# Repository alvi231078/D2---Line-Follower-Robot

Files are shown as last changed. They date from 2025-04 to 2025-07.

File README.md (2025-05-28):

# Intelligent Line Follower & Obstacle Color detector and Avoidance Robot

This robot uses IR sensors to follow a line, an ultrasonic sensor to detect obstacles, and a TCS3200 color sensor to detect colored zones (red, green, blue). If the color sensor is not connected, the robot will still function using IR and ultrasonic and IR sensors.

---

## 🛣 Line Following Logic

- **Sensor Input**:  
  - **Black surface** → `LOW`  
  - **White surface** → `HIGH`
  
- **Behavioral Responses**:
  - ➤ **Both sensors detect black** → Move straight
  - ➤ **One sensor detects white** → Adjust direction to stay on the line
  - ➤ **Both sensors detect white** → Line lost → Initiates recovery mode

---

## 🚧 Obstacle Avoidance Protocol

When an object is detected within **30-cm** using an ultrasonic sensor:

1. ➤ **Right Turn** – Exit the line path
2. ➤ **Forward Motion** – Navigate alongside the obstacle
3. ➤ **Left Turn** – Re-align with the original path
4. ➤ **Forward Motion** – Search and lock back onto the line

---

## 🎨 Color Sensor Behavior

If the optional TCS3200 color sensor is connected, the robot also responds to color:

- **Red** → Stop for 2 seconds  
- **Green** → Move forward faster  
- **Blue** → Turn right  
- **Unknown / No color** → Continue with normal behavior

> If the sensor is not connected, the robot continues using only IR and ultrasonic sensors.

---

## 🔌 Wiring Connections

### 🟦 Arduino UNO Pins

| Component | Pin on Arduino | Description |
|---|---|---|
| Left Motor | 9 | Left motor forward (PWM capable) |
| | 10 | Left motor backward |
| Right Motor | 5 | Right motor forward (PWM capable) |
| | 6 | Right motor backward |
| IR Sensor (Left)  | 2 | Digital input |
| IR Sensor (Right) | 3 | Digital input |
| Ultrasonic Sensor | 7 | Trigger pin |
| | 8 | Echo pin |
| Color Sensor S0 | 4 | Frequency scaling control |
| Color Sensor S1 | A0 | Frequency scaling control |
| Color Sensor S2 | A1 | Color filter selection |
| Color Sensor S3 | A2 | Color filter selection |
| Color Sensor OUT  | A3 | Frequency output |

---

## 🔋 Power Supply

- **Motors** should be powered using an external 6–12V battery (e.g., Li-Po).
- **Arduino UNO** can be powered via USB or VIN pin from the same battery.
- **IR, Ultrasonic, and Color Sensors** use 5V from the Arduino.

---

## ⚙️ Key Features

- ⏱️ **Non-Blocking Timers** – Efficient use of `millis()` for delay-free recovery  
- 🪛 **Debug with Ease** – Real-time diagnostics via `Serial Monitor`  
- 📦 **Modular Codebase** – Clear, reusable, and well-documented functions  

---

## 👨‍💻 Contributors

| Name | Title | Institution |
|---|---|---|
| **Md Ratul Ahmed Alvi** | Electronics Engineering Student  | Hochschule Hamm-Lippstadt |
| **Md Jubair Salehin Razin** | Electronics Engineering Student  | Hochschule Hamm-Lippstadt |
| **Faysal Ahammed Tonmoy** | Electronics Engineering Student  | Hochschule Hamm-Lippstadt |
| **Soaib Ferdous** | Electronics Engineering Student  | Hochschule Hamm-Lippstadt |

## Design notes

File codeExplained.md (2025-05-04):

🚗 Line Follower Robot – Project Description
Your project is a Line Follower Robot enhanced with obstacle avoidance capabilities using a state machine-based control system. Here's how it works step-by-step:

🔌 Startup
The robot begins in the Idle state after being powered on.

It transitions to LineFollowing when it receives a start command.

🧠 Core Behavior
In LineFollowing, the robot uses infrared (IR) sensors to follow a black line on the ground.

If no obstacle is detected, it keeps following the line.

If an obstacle is detected (via an ultrasonic sensor), it enters the ObstacleDetected state.

🕹️ Obstacle Avoidance
The robot stops and rotates a servo motor to scan its surroundings (ScanDirections).

It collects distance data from different directions (ChooseDirection) and selects the best path.

It then enters the BypassObstacle process, which decides whether to go right or left depending on available space.

🔄 Right or Left Bypass
In either RightBypass or LeftBypass, the robot:

Slightly turns in the chosen direction.

Moves forward, makes multiple turns to go around the obstacle.

Ends by searching for the original line again using its IR sensors.

👁️ Line Reacquisition
In LookForLineIR, the robot scans for the line.

Once the line is found (FinishBypass), it exits the bypass routine.

It returns to LineFollowing to continue on its path.

🛑 Shutdown
If the stop button is pressed or the battery is low, the robot enters the Stop state and powers off.

🧩 Key Technologies Involved:
IR sensors – For line tracking.

Ultrasonic sensor – For detecting obstacles.

Servo motor – For rotating and scanning directions.

State machine – To manage complex behaviors cleanly and modularly.

### 📘 `EXPLAIN.md` – Line-by-Line Code Explanation

```markdown
# 📘 Code Explanation – Line-Following Robot with Obstacle Avoidance

This document explains each section of the Arduino code used for an intelligent robot that can follow lines and avoid obstacles using ultrasonic and IR sensors.

---

## 🔧 Pin Definitions for car

```cpp
#define motorPin1 9
#define motorPin2 10
#define motorPin3 5
#define motorPin4 6
```
- These pins control the two DC motors via an H-bridge (e.g., L298N).

```cpp
#define TRIG_PIN 7
#define ECHO_PIN 8
```
- Ultrasonic sensor pins: `TRIG` sends a pulse, `ECHO` receives it.

```cpp
#define IR_LEFT 2
#define IR_RIGHT 3
```
- Left and right IR sensors for line detection.

```cpp
#define OBSTACLE_DISTANCE_THRESHOLD 30   // cm
#define RECOVERY_TIMEOUT 3000            // ms
#define AVOID_TIMEOUT 5000               // ms
```
- Constants for obstacle distance threshold and recovery timeouts.

---

## 🏁 setup()

```cpp
void setup() {
  // Set motor, ultrasonic, and IR pins
  pinMode(...);
  Serial.begin(9600);
}
```
- Prepares all input/output pins.
- Starts serial monitor for debugging and logs.

---

## 🔄 loop()

```cpp
long distance = getDistance();
bool leftIR = digitalRead(IR_LEFT);
bool rightIR = digitalRead(IR_RIGHT);
```
- Reads obstacle distance and IR sensor values (`LOW` = black line).

### Logging

```cpp
Serial.print("Distance: ");
Serial.println(distance);
```
- Shows real-time sensor data in the Serial Monitor.

### Obstacle Check

```cpp
if (distance < OBSTACLE_DISTANCE_THRESHOLD) {
  avoidObstacle();
  return;
}
```
- If the robot sees an obstacle within 30 cm, it performs a detour.

### Line Following

```cpp
if (!leftIR && !rightIR) moveForward();
else if (!leftIR && rightIR) turnLeft();
else if (leftIR && !rightIR) turnRight();
else recoverLine();
```
- Line-following logic using 2 IR sensors.

---

## 📏 getDistance()

```cpp
digitalWrite(TRIG_PIN, HIGH);
long duration = pulseIn(ECHO_PIN, HIGH, 20000);
return duration * 0.034 / 2;
```
- Measures time taken for sound to bounce back and converts to distance.
- Includes timeout of 20 ms to avoid sensor hang.

---

## 🚗 Motor Functions

```cpp
moveForward()
stopMotors()
turnLeft()
turnRight()
```
- Control robot movement by setting motor pins HIGH or LOW.

---

## 🔀 avoidObstacle()

```cpp
turnRight(); delay(400);
moveForward(); check distance;
turnLeft(); delay(400);
moveForward(); delay(500);
recoverLine();
```
- Turns away from obstacle, moves forward beside it, then returns to line.
- Uses timeout to avoid getting stuck in obstacle avoidance mode.

---

## ♻️ recoverLine()

```cpp
spin right slowly until IR_LEFT or IR_RIGHT sees black
```
- Spins in place to search for the black line.
- Times out if line isn't found within `RECOVERY_TIMEOUT`.

---

## ✅ Built-In Safety & Reliability

- **Timeouts**: Prevent infinite loops (e.g. in line recovery).
- **Distance Thresholds**: Stops or avoids collisions.
- **Failsafe Spins**: Robot always tries to recover or move forward.

---

## 📚 Further Ideas

- Use 3 IR sensors (left, center, right) for smoother detection.
- Replace `delay()` with `millis()` for non-blocking movement.
- Add `analogWrite()` (PWM) for speed control.
- Add remote or app-based control override.

---

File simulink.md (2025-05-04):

# 🚗 Line Follower Robot using MATLAB Simulink

This project demonstrates how to simulate and deploy an autonomous **line follower vehicle** using **MATLAB Simulink** and **Arduino Uno**. It uses **IR sensors** to detect the line path and controls the direction of two DC motors via **L298N Motor Driver**.

## 🛠 Hardware Used

* Arduino Uno
* 2 × DC Motors
* L298N Dual H-Bridge Motor Driver
* 2 × IR Sensors (Digital)
* Jumper wires, breadboard
* Optional: Ultrasonic sensor, TCS3200/TCS34725 (future)

## 🧱 Simulink Blocks Used

* **Digital Input** (IR\_LEFT: D2, IR\_RIGHT: D3)
* **Digital Output** (Motor Pins: D5, D6, D9, D10)
* **Logic Gates** (NOT, AND)
* **Multiport Switch**
* **Constant Blocks** (simulate logic levels)
* **Goto/From Tags** (signal routing)
* **Switch Block** (decision logic for motor direction)

## 🧠 Logic Overview

### IR Sensor Logic:

| IR\_LEFT | IR\_RIGHT | Action |
| --- | --- | --- |
| 0 | 0 | Stop |
| 0 | 1 | Turn Left |
| 1 | 0 | Turn Right |
| 1 | 1 | Move Forward |

### Motor Logic:

* Each motor has 2 input pins controlled through **multiport switches**.
* Based on the IR logic, control signals are routed to the motor inputs to drive the vehicle in the required direction.

## ✅ Current Features

* Complete **IR-based line-following logic**
* Simulates **four movement states**: Stop, Left, Right, Forward
* Multiport logic linked to motor pins:

  * Motor A: D9 (IN1), D10 (IN2)
  * Motor B: D5 (IN3), D6 (IN4)
* Built using modular **logic blocks** for learning and clarity

## 🧪 How to Test

1. Open the `line_follower_vehicle_Simulink.slx` in Simulink.
2. Ensure **Simulink Support Package for Arduino** is installed.
3. Set **hardware board** to "Arduino Uno" in Model Settings.
4. Use simulation or **Deploy to Hardware**.
5. Place the robot on a black line and observe motor reaction to IR input conditions.

## 🔮 Future Enhancements

* Add **Ultrasonic sensor** (`HC-SR04`) with **servo motor** for obstacle detection
* Add **Color Detection Sensor** (`TCS3200` or `TCS34725`) for object interaction
* Apply **PID control** for smoother turns
* Optimize logic using **Stateflow**

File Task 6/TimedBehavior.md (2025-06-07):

Timed Behavior – Task 6

This UPPAAL model simulates the obstacle-handling logic of the line-following robot, including:

Obstacle detection using distance

Color-based routing (red = avoid, blue = push)

Timed transitions using a clock x to simulate delays in real-world actuation (e.g., motor turning, scanning)

⏱️ Timing constraints are modeled using guards (x ≥ N) and invariants (x ≤ N) to reflect Arduino delays.

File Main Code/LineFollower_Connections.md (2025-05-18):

# Line Follower Robot with Motor Driver and IR Sensors

This project is a simple line follower robot using two digital IR sensors and a motor driver to control two DC motors (left and right). The robot follows a black line on a white surface by reading sensor inputs and controlling motor speed and direction accordingly.

---

## Hardware Connections

### Motor Driver Pins
| Pin | Description |
|---|---|
| 10 | ENA - PWM Motor A (Left Motor Speed Control) |
| 11 | ENB - PWM Motor B (Right Motor Speed Control)  |
| 5 | IN1 - Motor A Input 1 (Left Motor Direction) |
| 6 | IN2 - Motor A Input 2 (Left Motor Direction) |
| 7 | IN3 - Motor B Input 1 (Right Motor Direction)  |
| 8 | IN4 - Motor B Input 2 (Right Motor Direction)  |

### IR Sensor Pins (Digital)
| Pin | Description |
|---|---|
| 3 | Left IR Sensor |
| 4 | Right IR Sensor |

---

## Speed Settings

| Variable | Value | Description |
|---|---|---|
| `baseSpeed` | 65 | Normal forward speed (PWM) |
| `maxSpeed` | 90 | Maximum speed (not used in code) |
| `reverseSpeed` | 60 | Speed when reversing |

---

## How It Works

- The robot reads the state of two IR sensors (`leftSensorPin` and `rightSensorPin`).
- Both sensors LOW: Robot moves forward.
- Left sensor HIGH, right sensor LOW: Robot turns left.
- Left sensor LOW, right sensor HIGH: Robot turns right.
- Both sensors HIGH: Robot reverses to search for the line.

---

## Functions

- `moveForward(speed)`: Drives both motors forward at the specified speed.
- `turnLeft(speed)`: Stops left motor and runs right motor forward to turn left.
- `turnRight(speed)`: Runs left motor forward and stops right motor to turn right.
- `moveBackward(speed)`: Drives both motors backward at the specified speed.

---

## Usage

1. Connect your motors and IR sensors as described in the Hardware Connections.
2. Upload the provided Arduino sketch to your microcontroller.
3. Place the robot on a black line on a white surface and power it on.
4. The robot will follow the line by continuously adjusting its motor speeds based on sensor inputs.

---

## Notes

- Make sure your IR sensors are calibrated properly for the surface colors.
- Adjust `baseSpeed` and `reverseSpeed` values if needed for better line tracking.
- `maxSpeed` is defined but not used in the current code. You can modify the code to utilize it if required.

---

## License

This project is open source and free to use.

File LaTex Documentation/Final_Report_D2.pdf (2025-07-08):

# Design and Implementation of a Line Following and Obstacle Avoidance Robot

## ( Final Technical Report)

Team D2: Faysal Ahammed Tonmoy, Jubair Salehin Razin, Md Ratul Ahmed Alvi, Soaib Ferdous Prototyping and Systems Engineering
BSc Electronic Engineering Hochschule Hamm-Lippstadt, Lippstadt, Germany

Abstract—This paper presents the design, development, and implementation of an Arduino-based robot capable of following a black line and avoiding obstacles in its path. The system integrates IR sensors for line detection and an ultrasonic sensor mounted on a servo motor for environmental scanning. The robot’s decision-making algorithm enables smooth path-following while dynamically reacting to obstacles. Both hardware and software components were prototyped virtually before realworld testing. Results show reliable performance in various test scenarios.

Index Terms—Line follower robot, Obstacle avoidance, Arduino, Servo motor, Ultrasonic sensor

I. SYSTEM MODELING USING SYSML

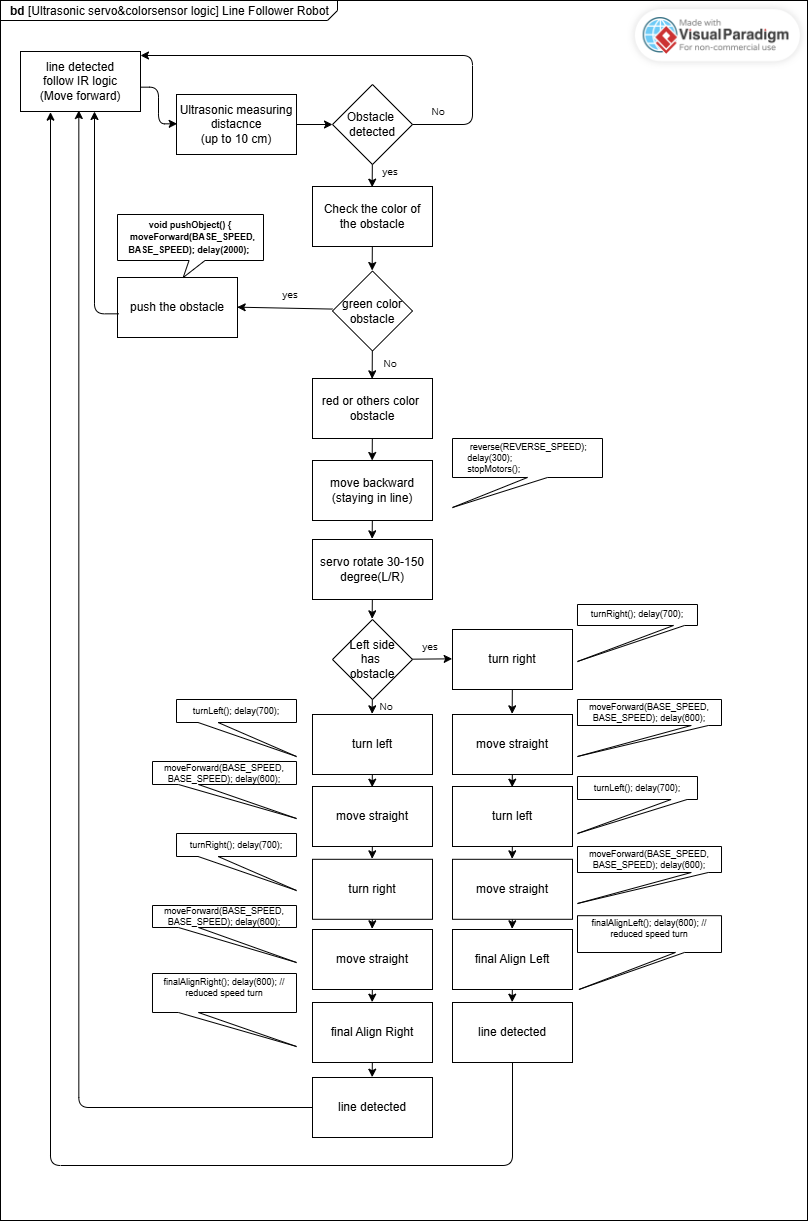
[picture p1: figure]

Fig. 1. Overall System Block Diagram of the Robot

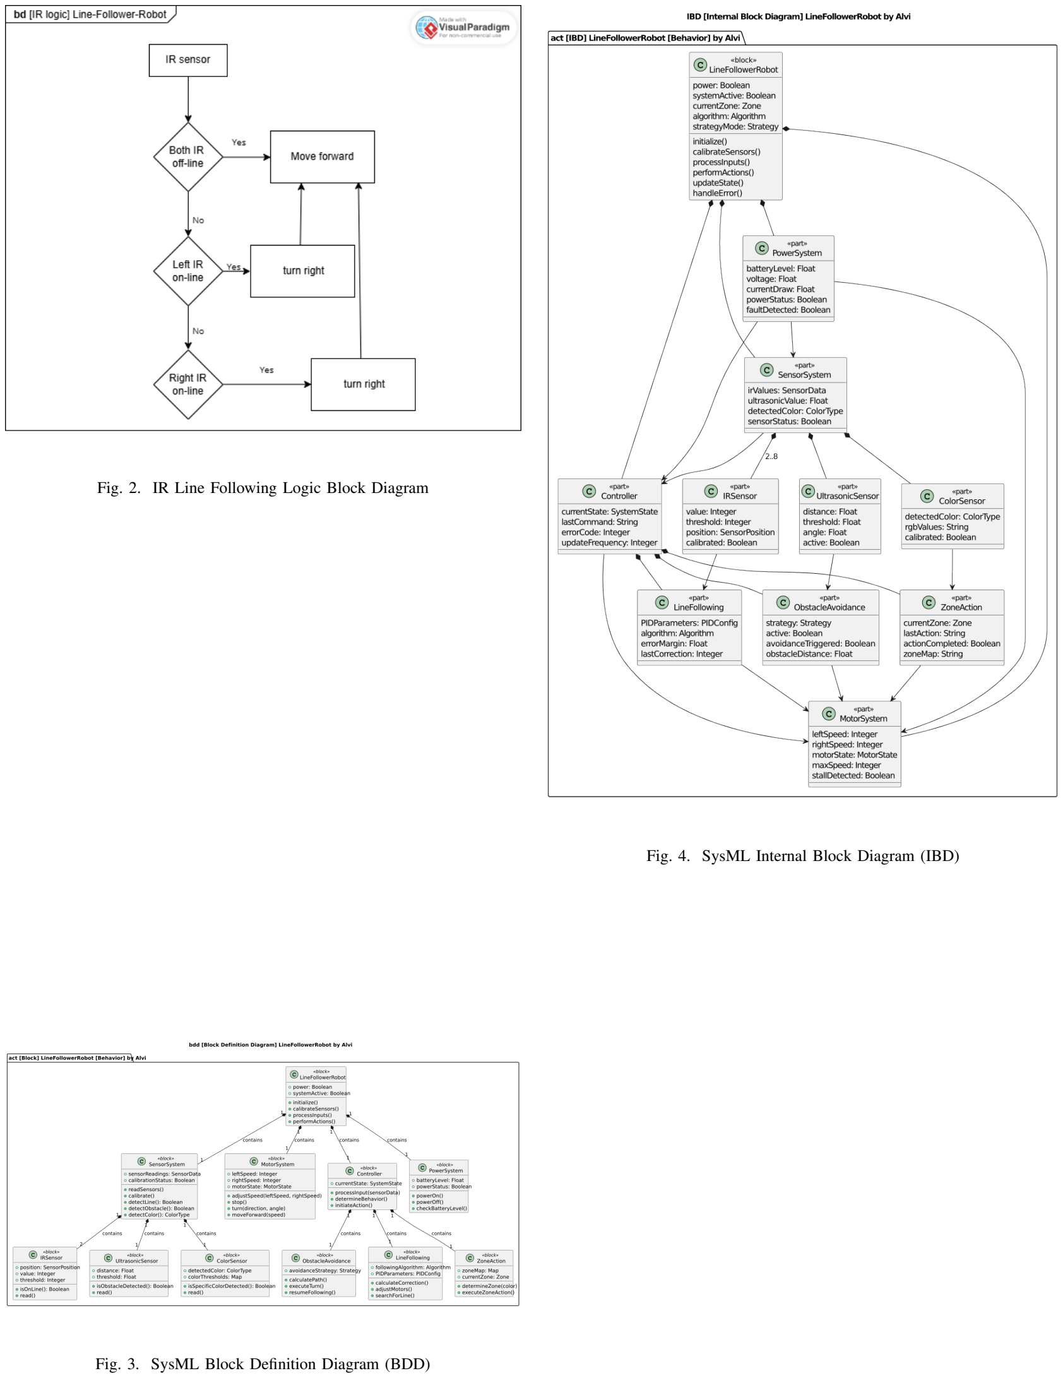
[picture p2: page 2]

Fig. 2. IR Line Following Logic Block Diagram

Fig. 3. SysML Block Definition Diagram (BDD)

Fig. 4. SysML Internal Block Diagram (IBD)

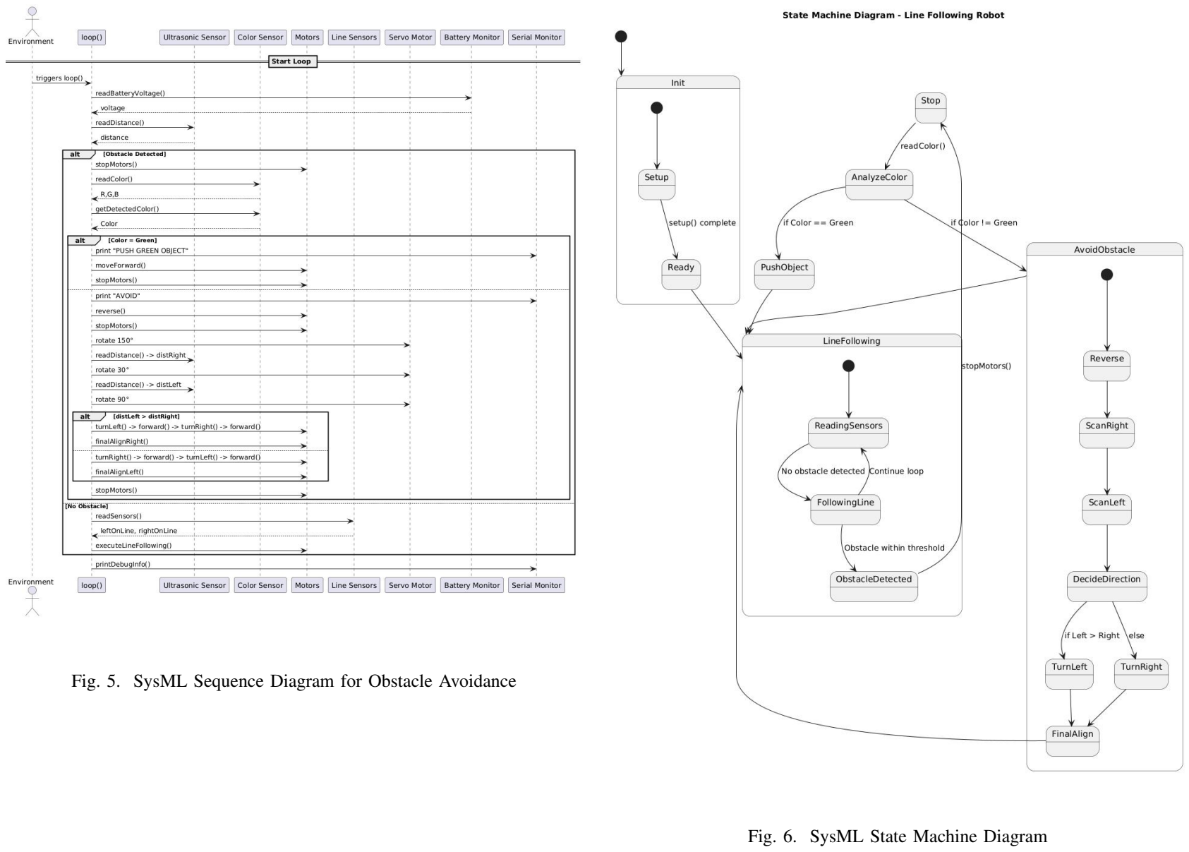
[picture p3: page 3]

Fig. 5. SysML Sequence Diagram for Obstacle Avoidance

Fig. 6. SysML State Machine Diagram

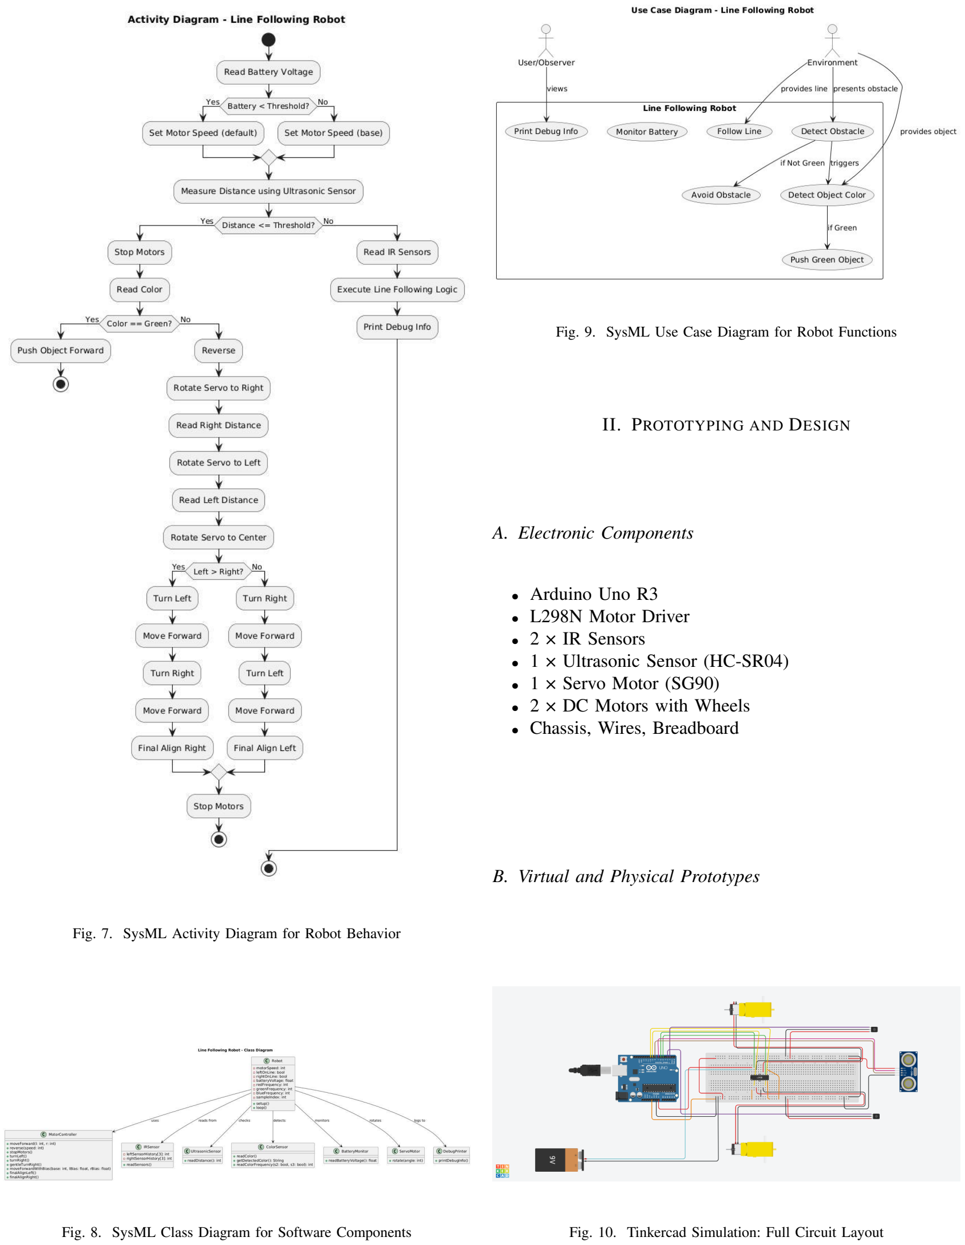
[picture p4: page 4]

Fig. 7. SysML Activity Diagram for Robot Behavior

Fig. 8. SysML Class Diagram for Software Components

Fig. 9. SysML Use Case Diagram for Robot Functions

II. PROTOTYPING AND DESIGN

A. Electronic Components
- Arduino Uno R3
- L298N Motor Driver
- 2 × IR Sensors
- 1 × Ultrasonic Sensor (HC-SR04)
- 1 × Servo Motor (SG90)
- 2 × DC Motors with Wheels
- Chassis, Wires, Breadboard
B. Virtual and Physical Prototypes

Fig. 10. Tinkercad Simulation: Full Circuit Layout

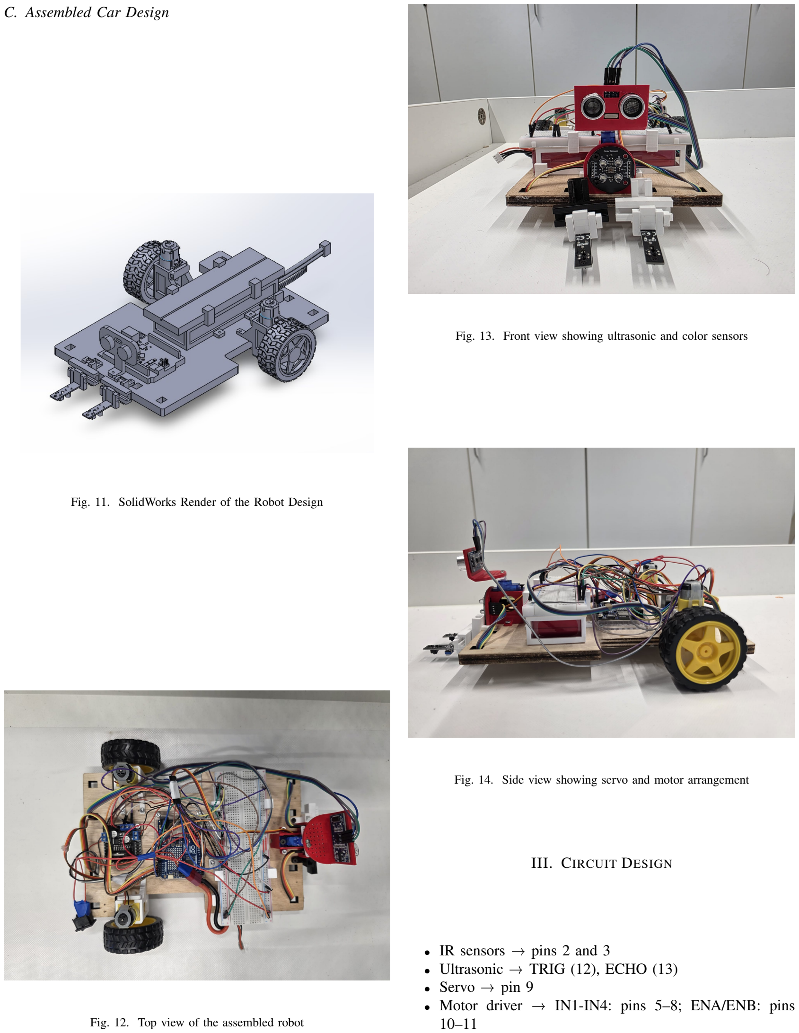
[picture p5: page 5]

C. Assembled Car Design

Fig. 11. SolidWorks Render of the Robot Design

Fig. 12. Top view of the assembled robot

Fig. 13. Front view showing ultrasonic and color sensors

Fig. 14. Side view showing servo and motor arrangement

III. CIRCUIT DESIGN

- IR sensors pins 2 and 3
- Ultrasonic TRIG (12), ECHO (13)
- Servo pin 9
- Motor driver IN1-IN4: pins 5–8; ENA/ENB: pins 10–11

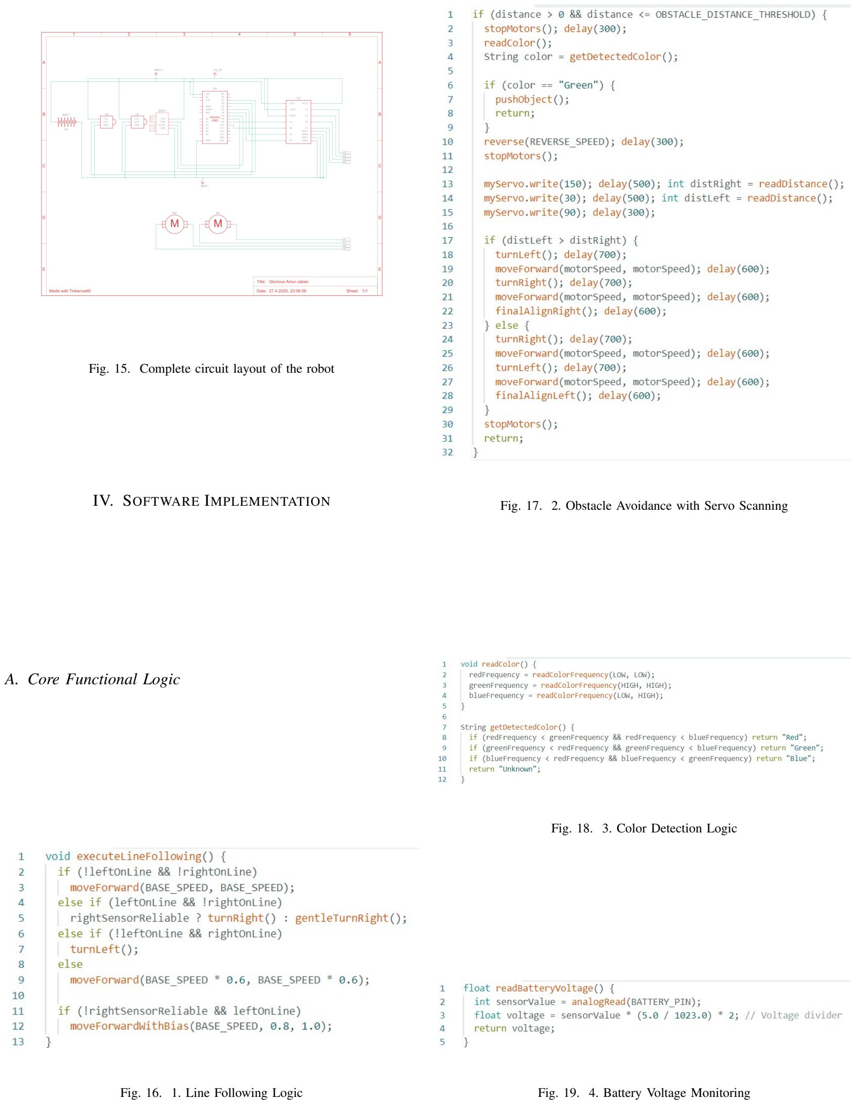
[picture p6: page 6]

Fig. 15. Complete circuit layout of the robot

IV. SOFTWARE IMPLEMENTATION

A. Core Functional Logic

Fig. 16. 1. Line Following Logic

Fig. 17. 2. Obstacle Avoidance with Servo Scanning

Fig. 18. 3. Color Detection Logic

Fig. 19. 4. Battery Voltage Monitoring

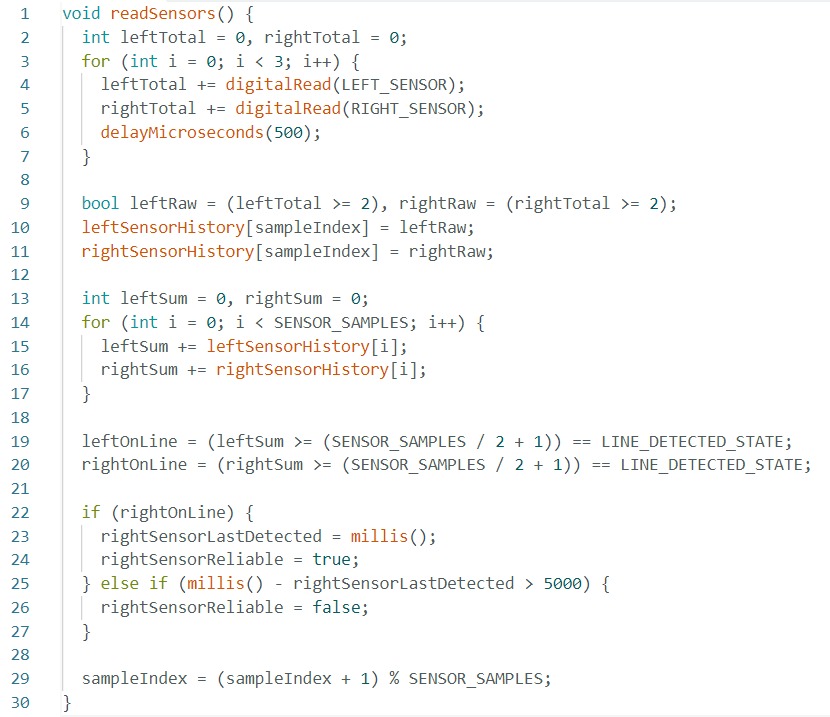
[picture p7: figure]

Fig. 20. 5. Sensor Filtering for Stability

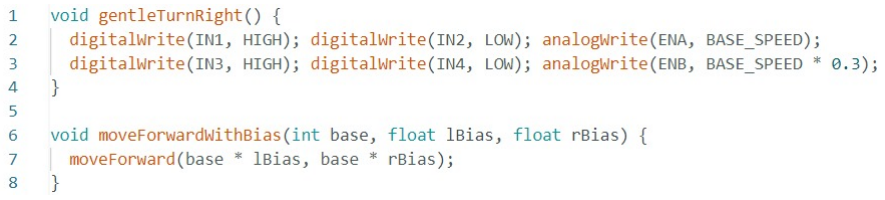
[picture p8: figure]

Fig. 21. 6. Differential Speed for Smooth Turns

B. A. UPPAAL Simulation

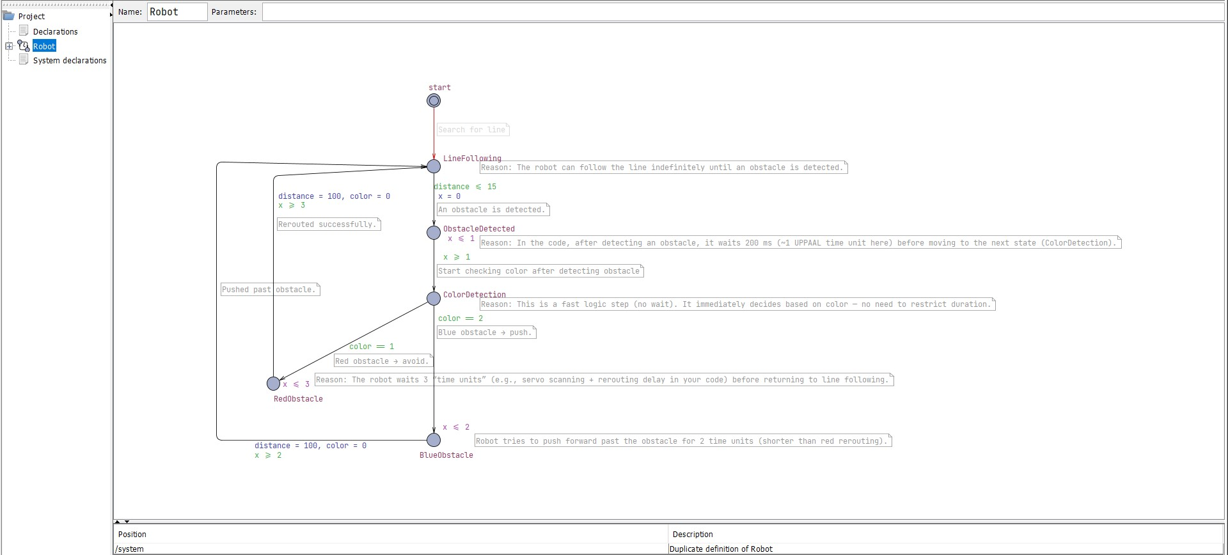
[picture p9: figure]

Fig. 22. UPPAAL Timed Automata Model for Robot Control

C. B. LTspice Simulation

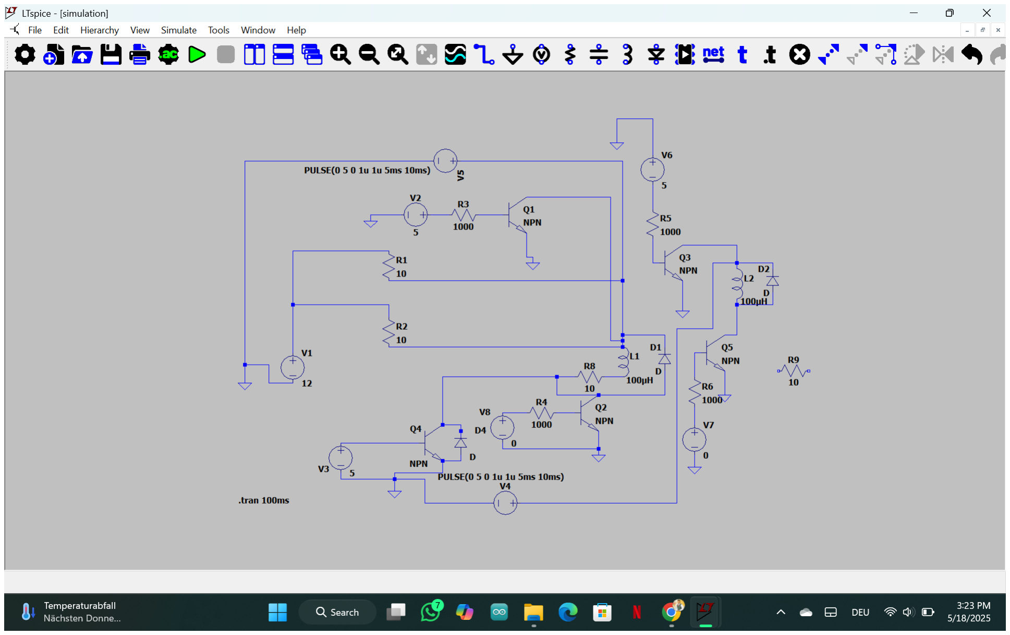
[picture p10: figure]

Fig. 23. LTspice Motor Driver Circuit Simulation

V. GIT USAGE AND COLLABORATION
- Jubair Salehin Razin: Simulation, testing, software logic, hardware integration
- Md Ratul Ahmed Alvi: Arduino coding, debugging, wiring and logic testing
- Faysal Ahammed Tonmoy: Documentation, CAD, simulations, integration
- Soaib Mahin Ferdous: Diagram creation, documentation, support tasks
Team Member | Commits
Faysal Ahammed Tonmoy | 90
Jubair Salehin Razin | 148
Md Ratul Ahmed Alvi | 162
Soaib Mahin Ferdous | 36
Total | 436
TABLE I
GITHUB COMMITS BY TEAM MEMBERS

VI. KEY ACHIEVEMENTS

- Built a reliable, intelligent robot system
- Designed and printed all mechanical parts in SolidWorks
- Simulated logic and hardware in Tinkercad, UPPAAL, LTspice
- Documented system architecture using SysML
- Worked collaboratively using GitHub

VII. CONCLUSION AND FUTURE WORK

The robot successfully integrates sensor data and motor control to follow a black line while avoiding obstacles. Future enhancements may include path memory, camera-based vision, Bluetooth control, and autonomous charging.

ACKNOWLEDGMENT

We sincerely thank our professor for their guidance, feedback, and encouragement throughout this project. We also appreciate the support from lab assistants and the facilities provided by Hochschule Hamm-Lippstadt, which were essential to our development and testing. Finally, we acknowledge the teamwork and dedication of all members that made this project a success.

REFERENCES

[1] Arduino Documentation. https://www.arduino.cc/en/Guide
[2] Tinkercad Simulation. https://www.tinkercad.com
[3] Uppaal Model Checker. http://www.uppaal.org/
[4] LTspice | Simulator. | https://www.analog.com/en/design-center/
design-tools-and-calculators/ltspice-simulator.html (https://www.analog.com/en/design-center/design-tools-and-calculators/ltspice-simulator.html)

DECLARATION OF ORIGINALITY
We hereby declare that this report is our own work and that we have acknowledged all sources used.
Faysal Ahammed Tonmoy
Jubair Salehin Razin
Md Ratul Ahmed Alvi
Soaib Ferdous

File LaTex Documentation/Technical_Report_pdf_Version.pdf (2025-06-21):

# Design and Implementation of a Line Following and Obstacle Avoidance Robot

## (Technical Report)

Team D2: Faysal Ahammed Tonmoy, Jubair Salehin Razin, Md Ratul Ahmed Alvi, Soaib Ferdous Prototyping and Systems Engineering BSc Electronic Engineering Hochschule Hamm-Lippstadt
Lippstadt, Germany

Abstract—This paper presents the design, development, and implementation of an Arduino-based robot capable of following a black line and avoiding obstacles in its path. The system integrates IR sensors for line detection and an ultrasonic sensor mounted on a servo motor for environmental scanning. The robot’s decision-making algorithm enables smooth path-following while dynamically reacting to obstacles. Both hardware and software components were prototyped virtually before real-world testing. Results show reliable performance in various test scenarios.

Index Terms—Line follower robot, Obstacle avoidance, Arduino, Servo motor, Ultrasonic sensor

I. INTRODUCTION

Line-following and obstacle-avoiding robots are fundamental projects in the field of robotics and embedded systems. These robots offer practical insights into sensor integration, motor control, decision-making algorithms, and real-time behavior. Such applications are widely used in industrial automation, delivery robots, and warehouse management systems.

This project focuses on the design and development of a mobile robot that can autonomously follow a predefined path while detecting and avoiding obstacles using infrared (IR) and ultrasonic sensors. The integration of hardware and software components was achieved through iterative prototyping, simulation (using Tinkercad), and formal verification using UPPAAL to ensure time-critical responsiveness.

The objective was to create a low-cost, Arduino-based robot capable of smart navigation in dynamic environments, with collaborative development managed via Git and GitHub.

II. SYSTEM MODELING USING SYSML

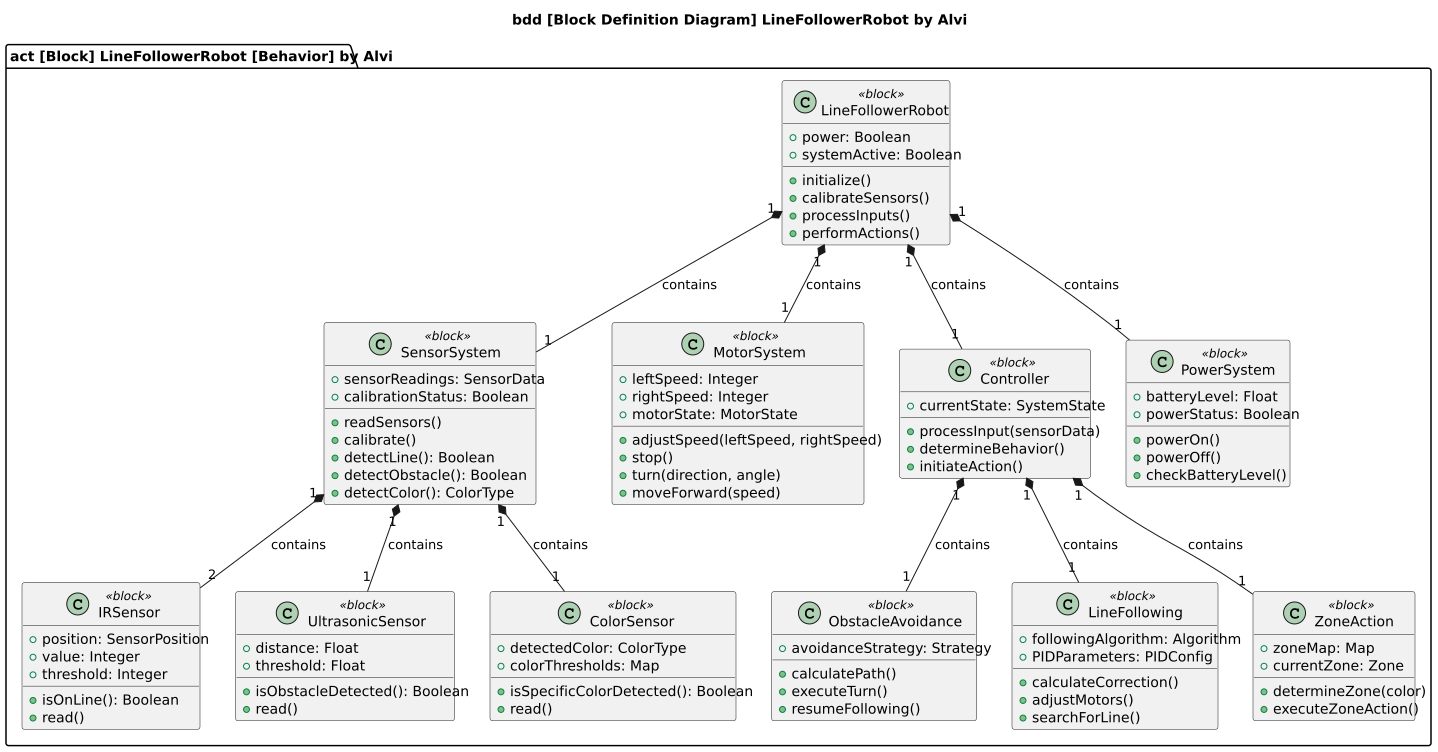
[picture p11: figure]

Fig. 1. SysML Block Definition Diagram (BDD)

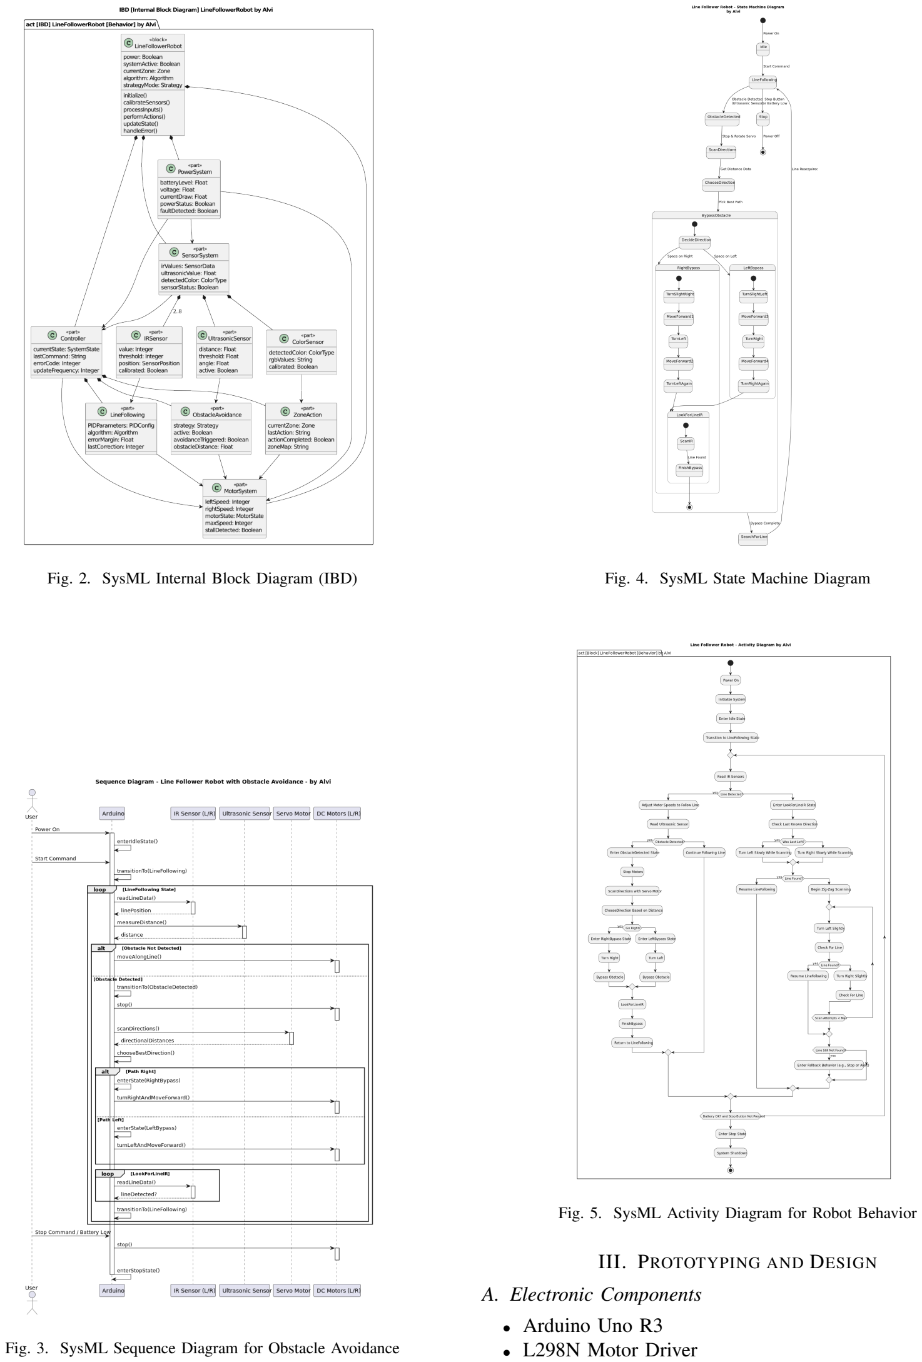
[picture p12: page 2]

Fig. 2. SysML Internal Block Diagram (IBD)

Fig. 3. SysML Sequence Diagram for Obstacle Avoidance

Fig. 4. SysML State Machine Diagram

Fig. 5. SysML Activity Diagram for Robot Behavior

III. PROTOTYPING AND DESIGN

A. Electronic Components
- Arduino Uno R3
- L298N Motor Driver

- 2 × IR Sensors
- 1 × Ultrasonic Sensor (HC-SR04)
- 1 × Servo Motor (SG90)
- 2 × DC Motors with Wheels
- Chassis, Wires, Breadboard
B. Virtual and Physical Prototypes

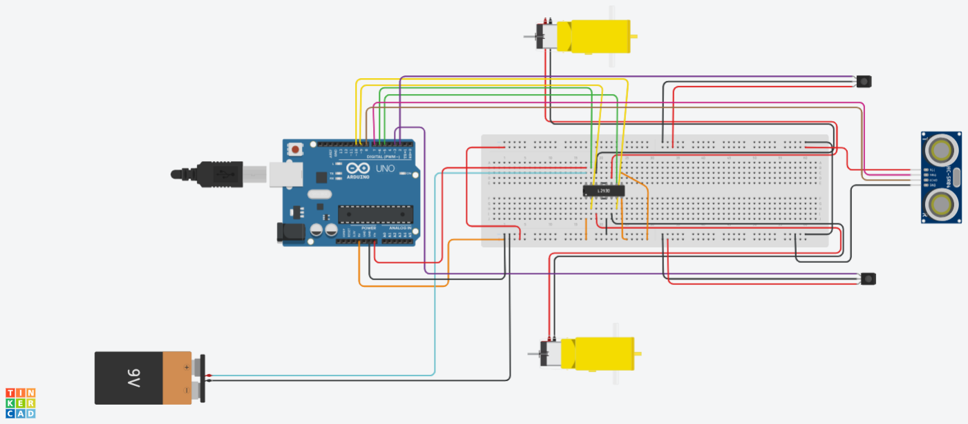
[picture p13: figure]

Fig. 6. Tinkercad Simulation: Full Circuit Layout

C. Assembled Car Design

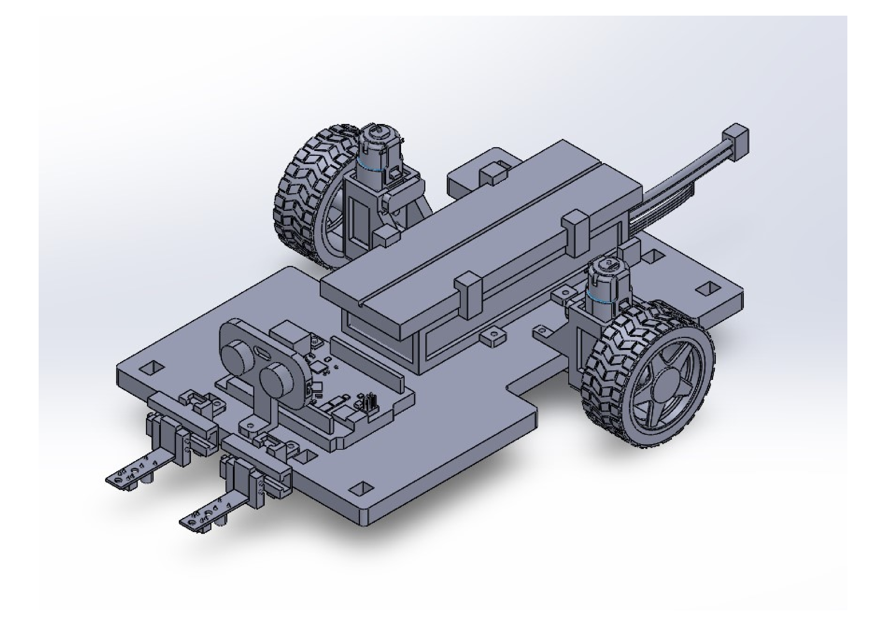
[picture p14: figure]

Fig. 7. Assembled Robot Car Design

The fully assembled robot car was modeled and visualized in SolidWorks 3D CAD software before physical construction. Each component—including the chassis, motor mounts, battery cover, sensor holders, and servo brackets—was individually designed to exact dimensions. These designs were then assembled virtually in SolidWorks to verify spatial alignment, mechanical fit, and wiring paths.
This digital mockup allowed us to detect and resolve potential mechanical interferences before 3D printing. The rendered model accurately represents the real-world robot structure and showcases the integration of all electronic and mechanical parts into a compact and modular design.

IV. CIRCUIT DESIGN

- IR sensors pins 2 and 3
- Ultrasonic TRIG (12), ECHO (13)
- Servo pin 9
- Motor driver IN1-IN4: pins 5–8; ENA/ENB: pins 10–11

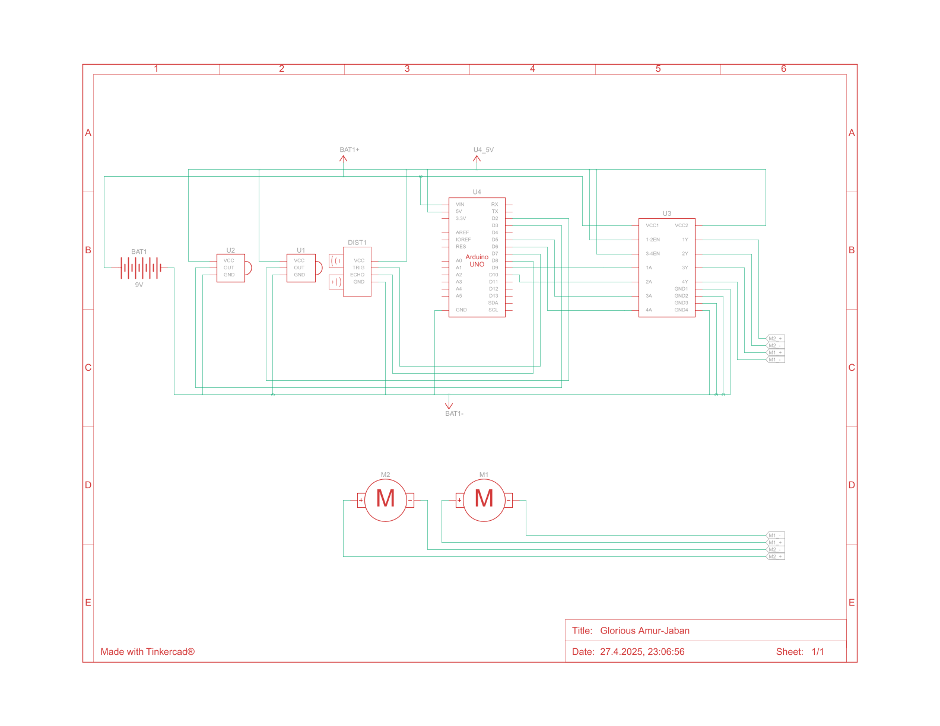
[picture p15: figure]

Fig. 8. Complete circuit layout of the robot

V. SOFTWARE IMPLEMENTATION
A. A. UPPAAL Simulation


Fig. 9. UPPAAL Timed Automata Model for Robot Control

To formally verify the robot’s behavior, a timed automata model was created in UPPAAL. The simulation captures key control states such as line following, obstacle detection, and turning logic with time constraints. By modeling transitions and clock conditions, we validated the robot’s response timing to avoid delays or missed decisions during operation. This ensures reliability in real-world dynamic scenarios.

B. B. LTspice Simulation

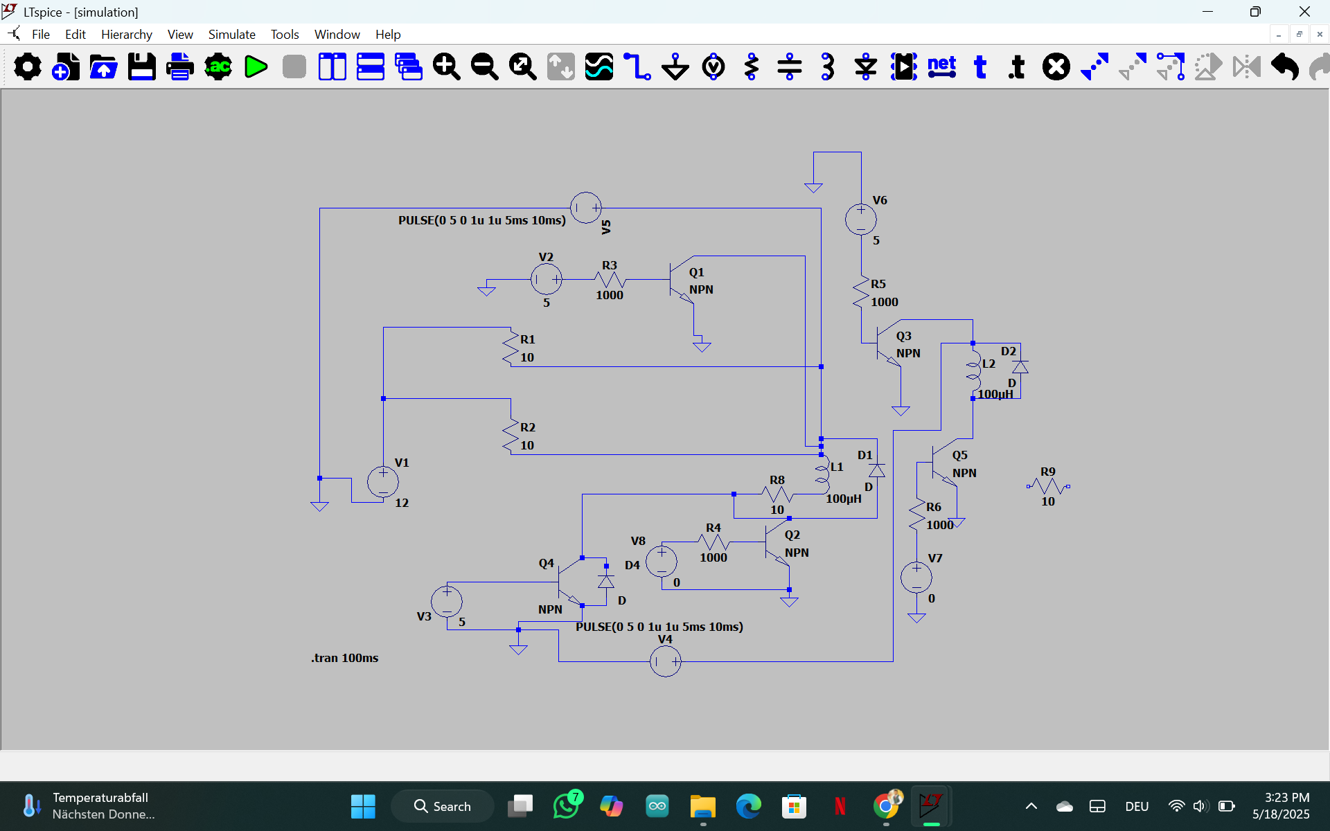
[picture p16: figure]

Fig. 10. LTspice Motor Driver Circuit Simulation

The motor driver circuit was simulated in LTspice to ensure proper voltage levels, current flow, and switching behavior before hardware implementation. This simulation helped verify the performance of the L298N driver in handling bidirectional DC motor control, confirming safe operation under load and validating protective components such as flyback diodes.

VI. GIT USAGE AND COLLABORATION
Version control and collaborative development were managed using Git and GitHub.
- Jubair Salehin Razin: Simulation,validation testing, Wiring and Software Implementation,Physical hardware assembly, component placement, chassis design.
- Md Ratul Ahmed Alvi: Arduino logic, Program Development / Algorithm Development, wiring, testing, and diagramming
- Faysal Ahammed Tonmoy: Documentation, circuit design, integration and 3D Design, LTspice Simulation, Wiring, LaTex Documentation.
- Soaib Mahin Ferdous: Supporting diagrams, documentation, modeling, Wiring.
Team Member | Commits
Faysal Ahammed Tonmoy | 82
Jubair Salehin Razin | 122
Md Ratul Ahmed Alvi | 162
Soaib Mahin Ferdous | 30
Total | 421
TABLE I
GITHUB COMMITS BY TEAM MEMBERS

VII. KEY ACHIEVEMENTS
- Built a reliable, intelligent robot system
- Designed and printed all mechanical parts in SolidWorks
- Simulated logic and hardware in Tinkercad, UPPAAL, LTspice
- Documented system architecture using SysML
- Worked collaboratively using GitHub

VIII. CONCLUSION AND FUTURE WORK
The robot successfully integrates sensor data and motor control to follow a black line while avoiding obstacles. Future enhancements may include path memory, camera-based vision, Bluetooth control, and autonomous charging.

ACKNOWLEDGMENT
We would like to thank our professor and lab assistants for their guidance and support throughout the development of this project.

REFERENCES

[1] Arduino Documentation. https://www.arduino.cc/en/Guide
[2] Tinkercad Simulation. https://www.tinkercad.com
[3] Uppaal Model Checker. http://www.uppaal.org/
[4] LTspice | Simulator. | https://www.analog.com/en/design-center/
design-tools-and-calculators/ltspice-simulator.html (https://www.analog.com/en/design-center/design-tools-and-calculators/ltspice-simulator.html)

DECLARATION OF ORIGINALITY
We hereby declare that this report is our own work and that we have acknowledged all sources used.

Faysal Ahammed Tonmoy
Jubair Salehin Razin
Md Ratul Ahmed Alvi
Soaib Mahin Ferdous

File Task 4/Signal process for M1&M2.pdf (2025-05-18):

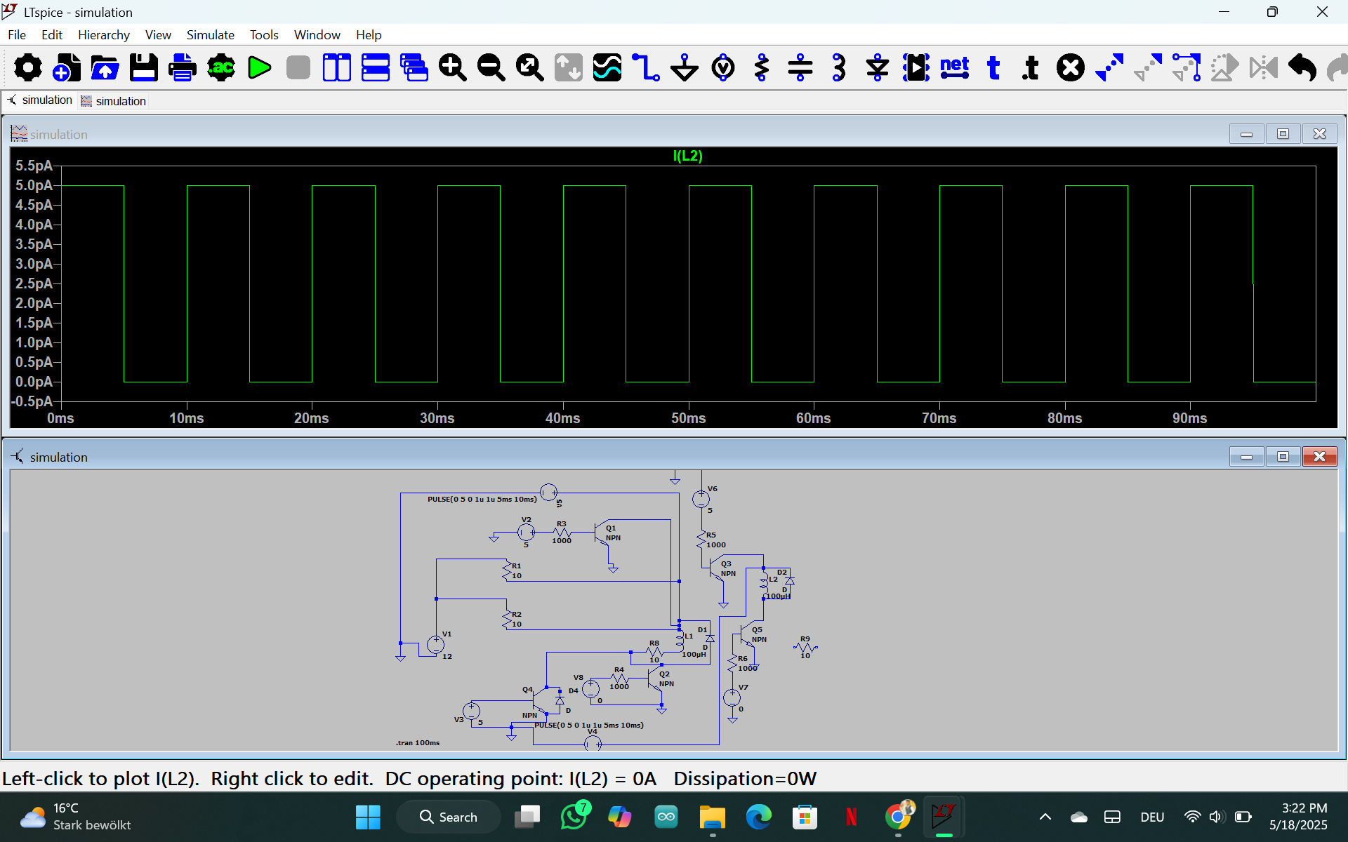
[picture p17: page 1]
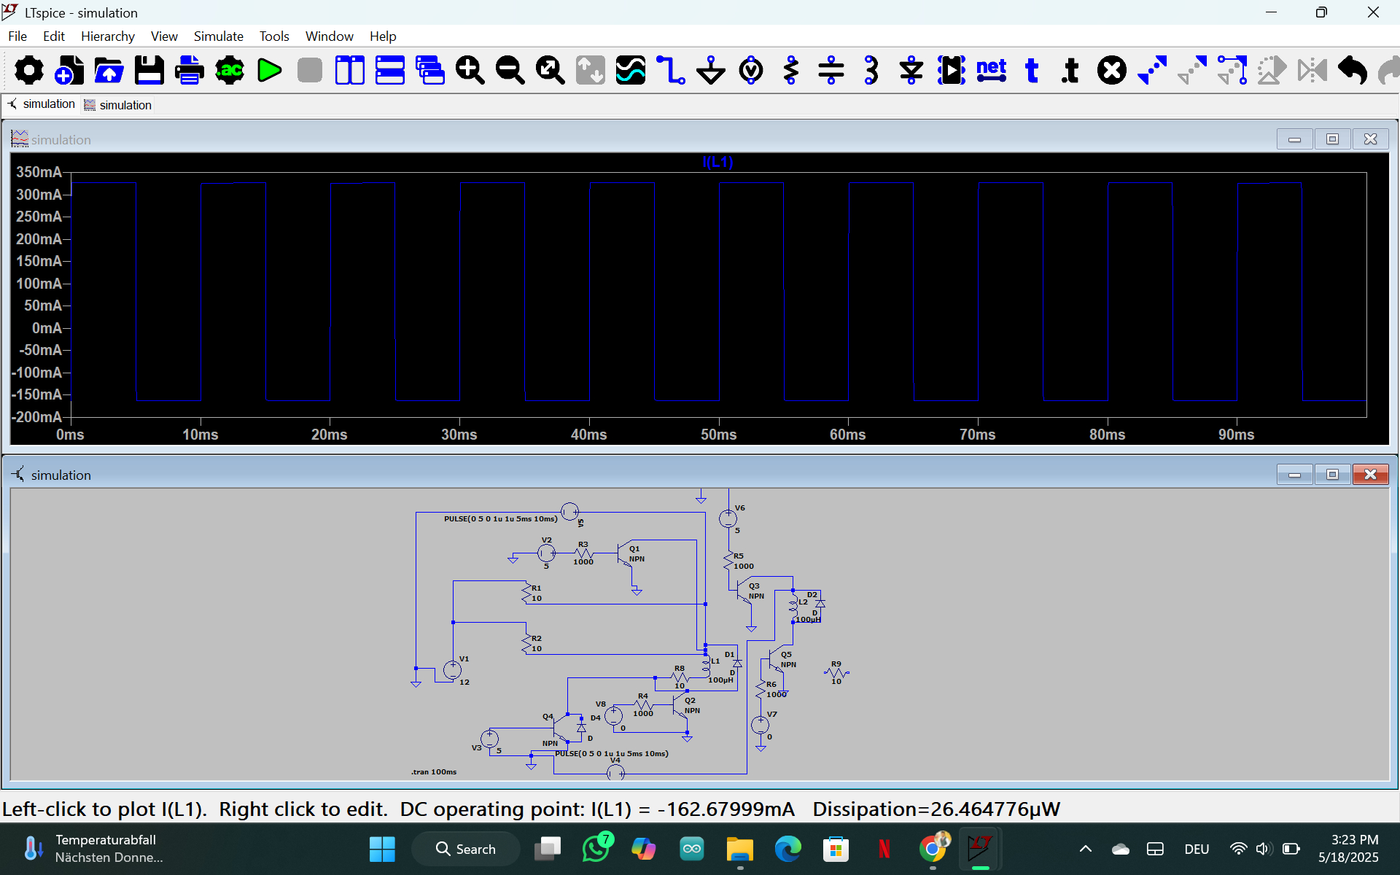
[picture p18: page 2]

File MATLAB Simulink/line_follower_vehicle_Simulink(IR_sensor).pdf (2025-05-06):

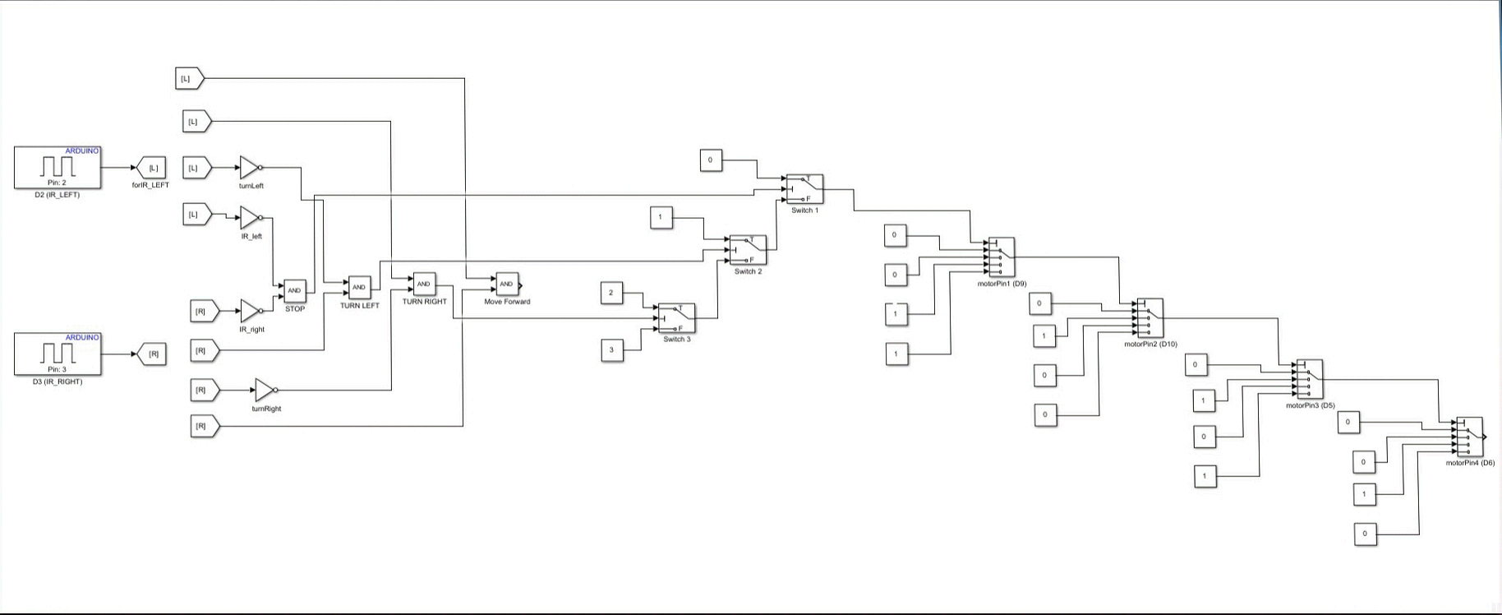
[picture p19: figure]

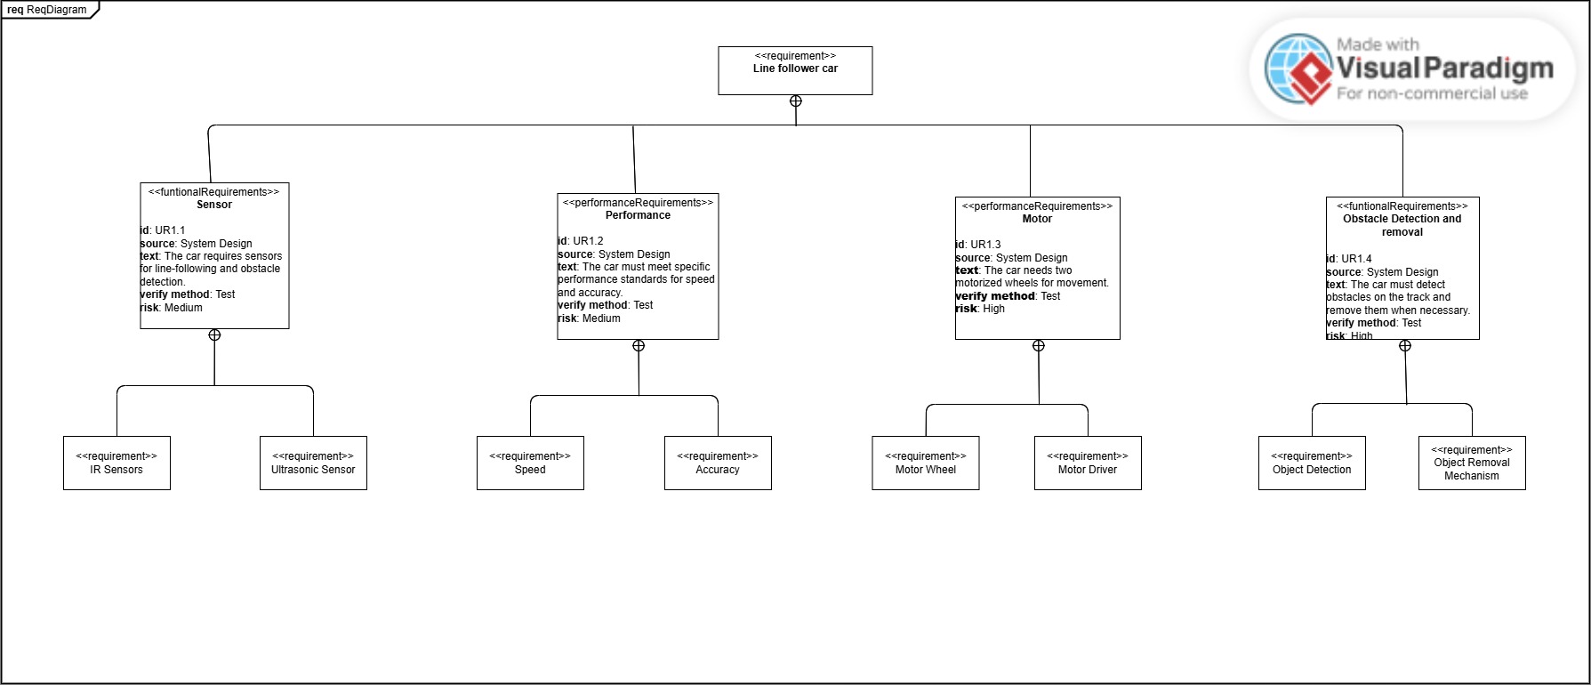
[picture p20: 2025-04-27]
SysML Diagrams and related files/Requirements_Diagram-version-1.jpg

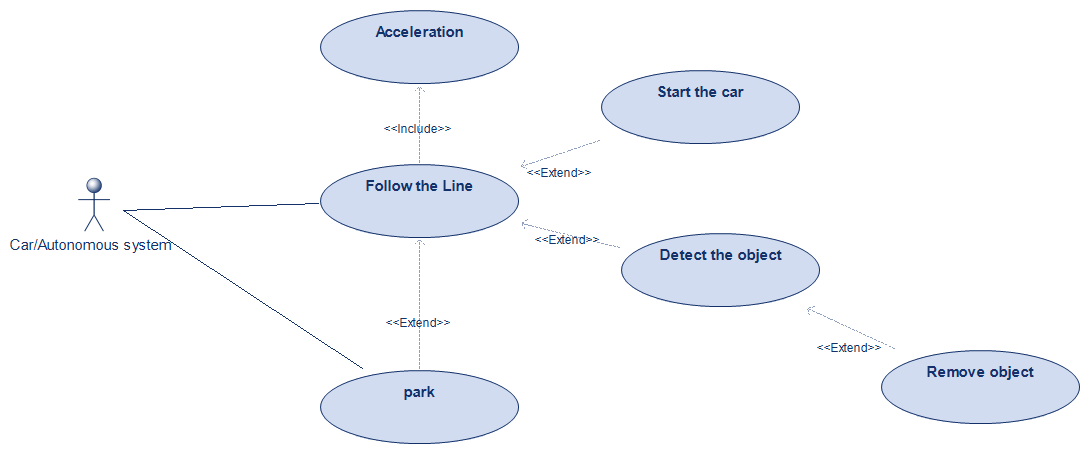
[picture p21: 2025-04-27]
SysML Diagrams and related files/Use_Case_Diagram.png

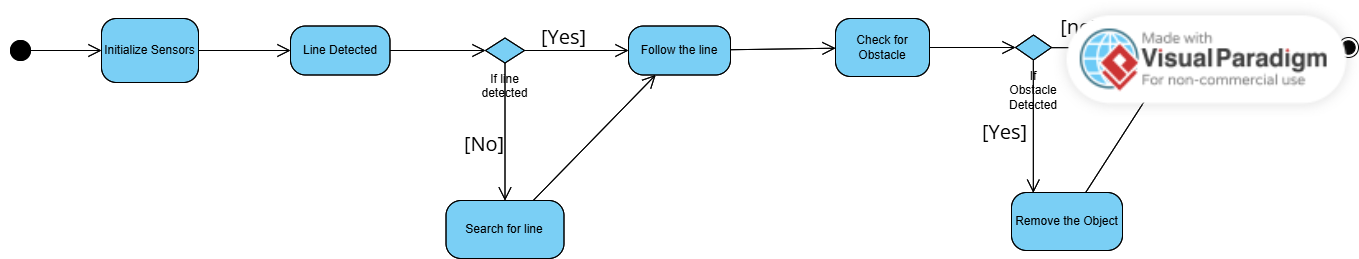
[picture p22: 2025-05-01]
Diagrams/activity-diagram-v1.png

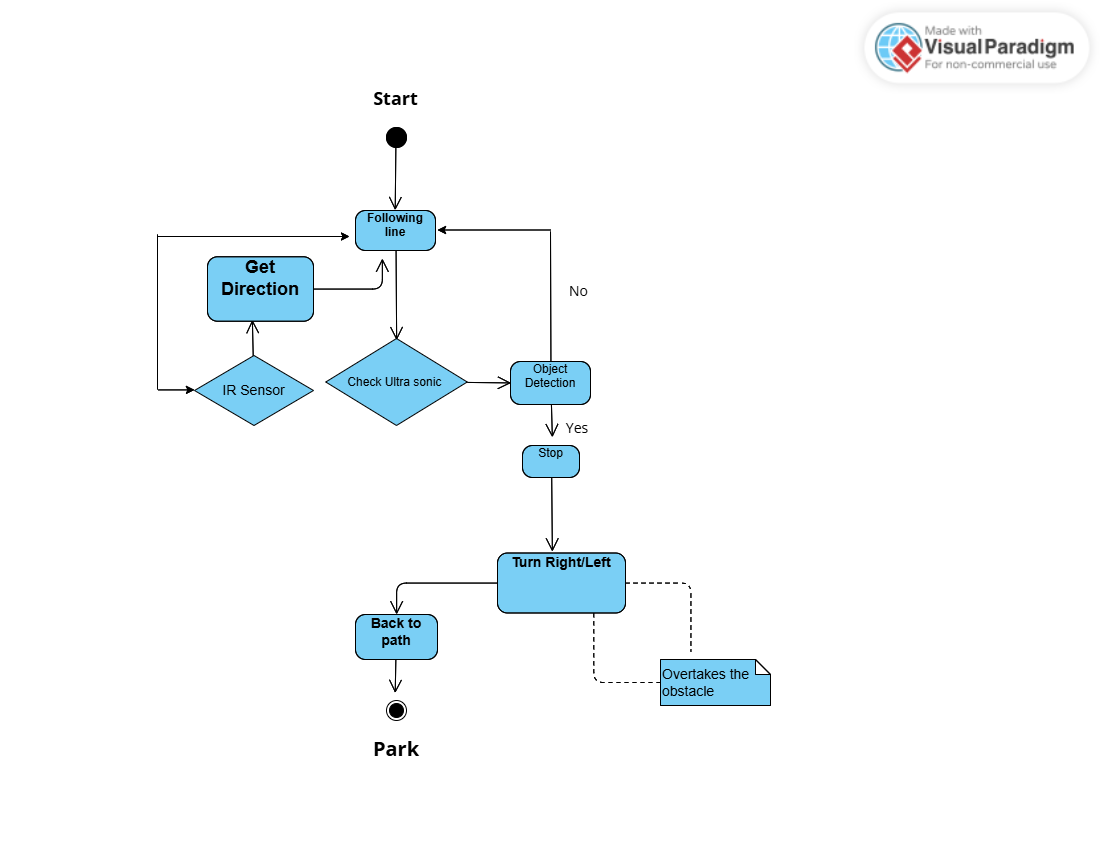
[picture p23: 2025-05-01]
SysML Diagrams and related files/State_Machine_diagram-v2.png

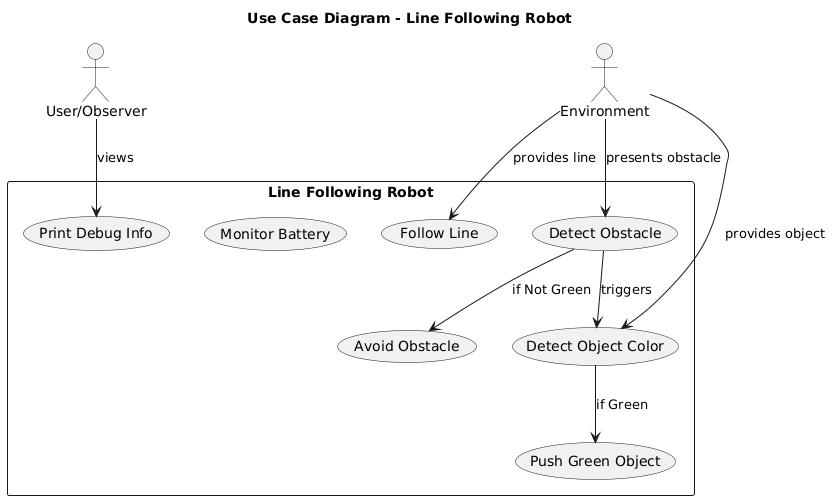
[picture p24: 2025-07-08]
Final SysML Diagram/Updated Final Use Case Diagram.jpeg

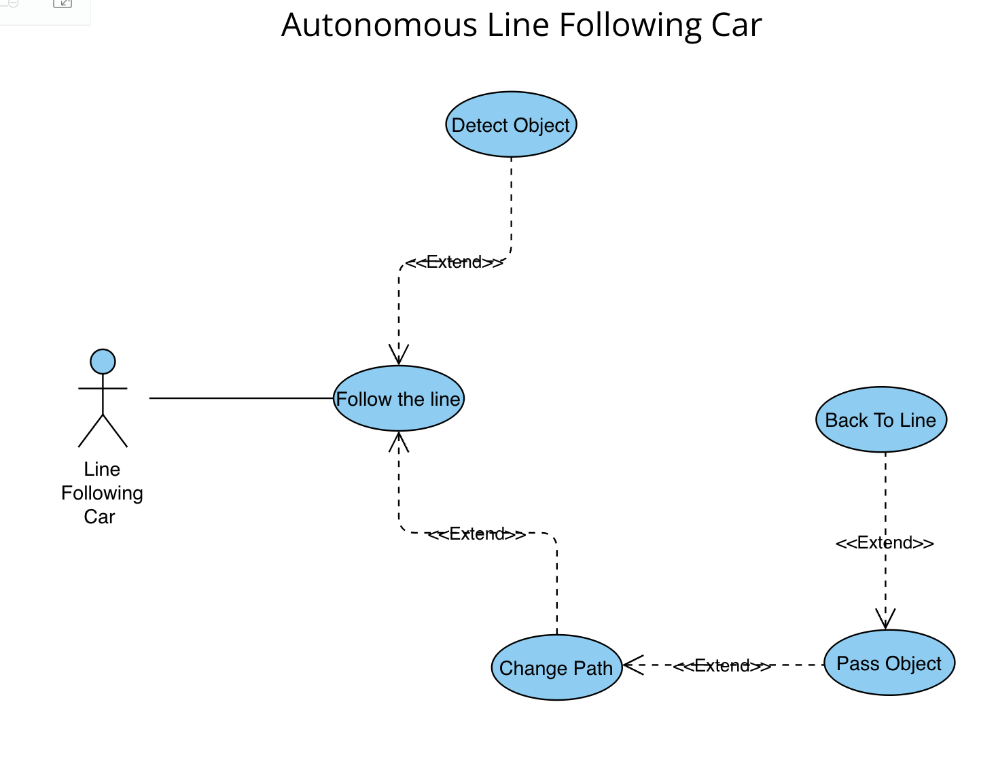
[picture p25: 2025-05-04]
SysML Diagrams and related files/Use_Case_Diagram_v2.png

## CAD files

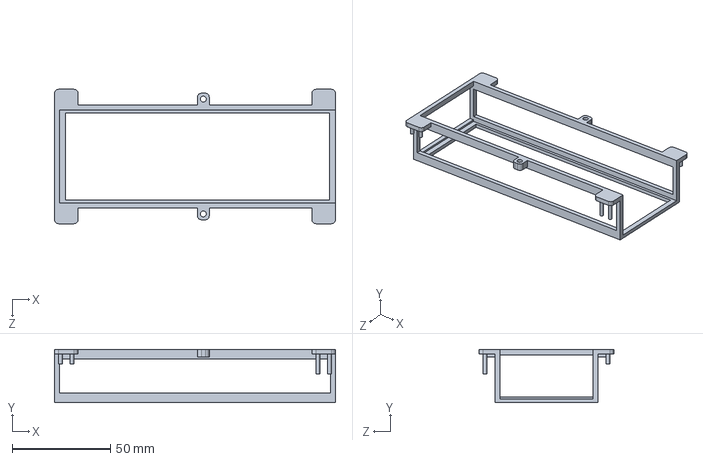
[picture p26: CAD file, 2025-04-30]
Task 1/final_FULL_battery_COVER solidpart.SLDPRT
142.9 x 27.2 x 68.4 mm

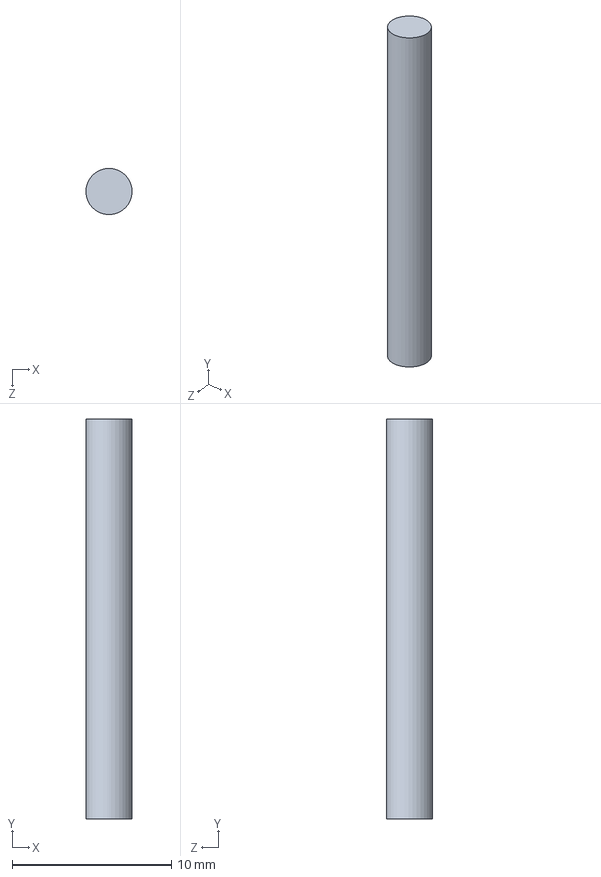
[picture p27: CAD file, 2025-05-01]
3D design for the car/6-motor holder pin solidpart.SLDPRT
2.90 x 25.1 x 2.90 mm

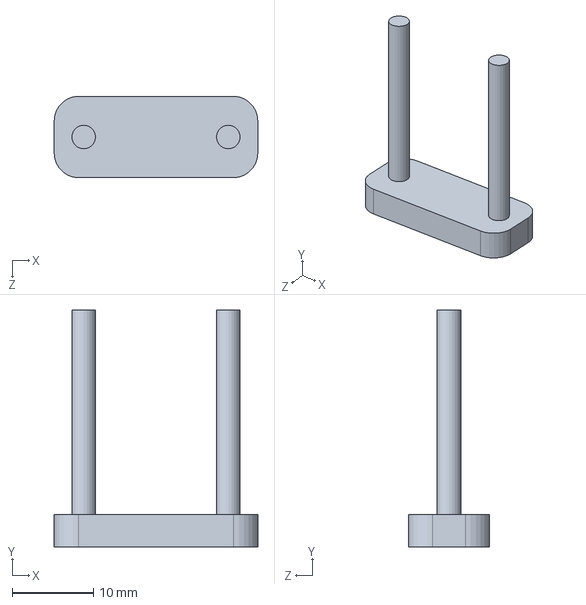
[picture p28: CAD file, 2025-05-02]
Task 1/6.1Motor holder pin updated-solidpart.SLDPRT
25.0 x 29.1 x 10.0 mm

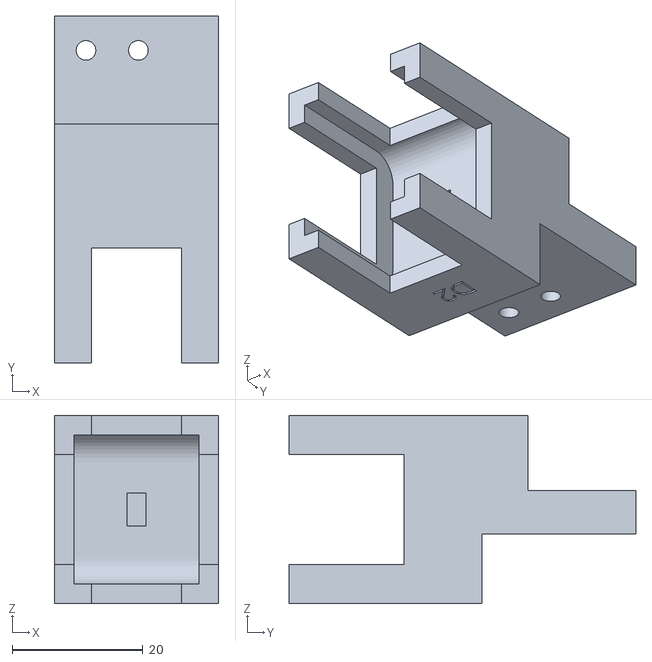
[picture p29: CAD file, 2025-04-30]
3D design for the car/motor_holder_top_first_side solidpart.STL
25.1 x 53.0 x 28.8

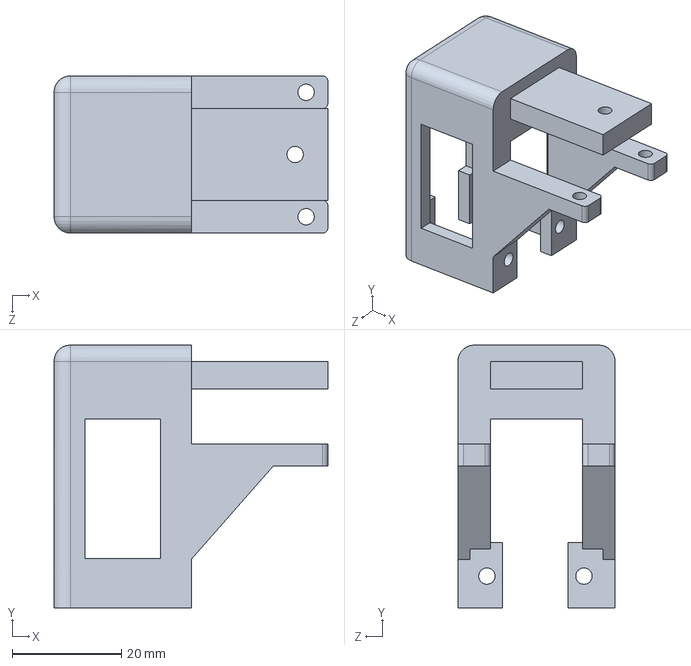
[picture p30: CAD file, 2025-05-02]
Task 1/5.1 motor holder updated.SLDPRT
50.1 x 48.1 x 28.8 mm

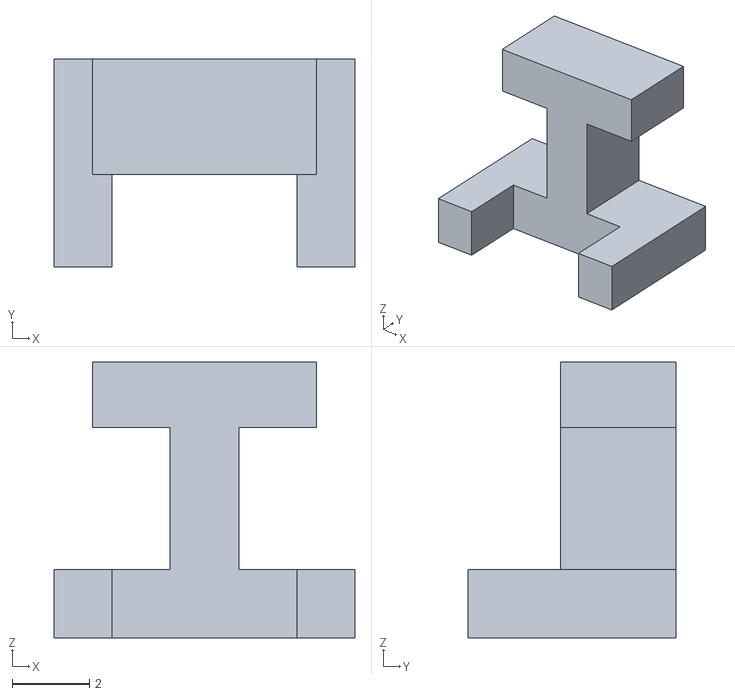
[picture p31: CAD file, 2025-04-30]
3D design for the car/new_ultrasonic_key solidpart.STL
7.80 x 5.40 x 7.15

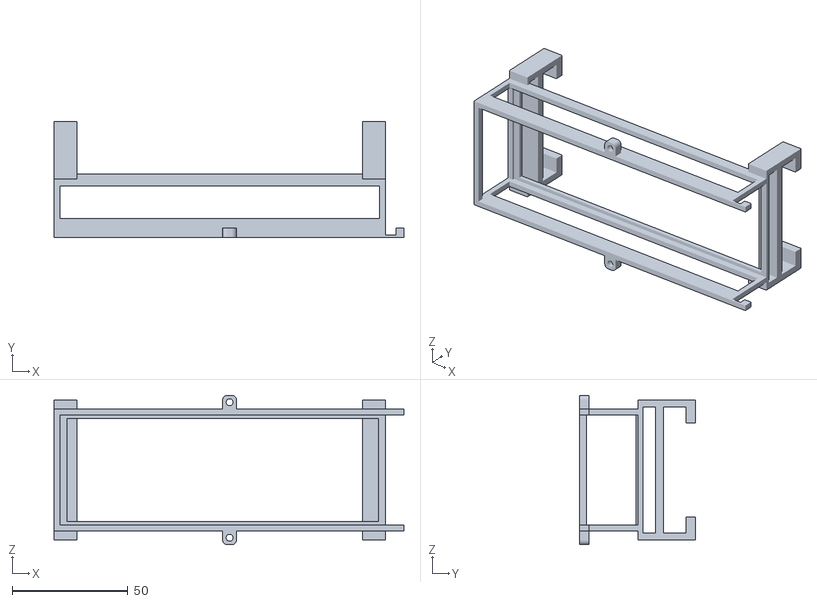
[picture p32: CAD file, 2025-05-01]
Task 1/Final_battery_cover with breadboard.STL
150.9 x 49.9 x 64.4

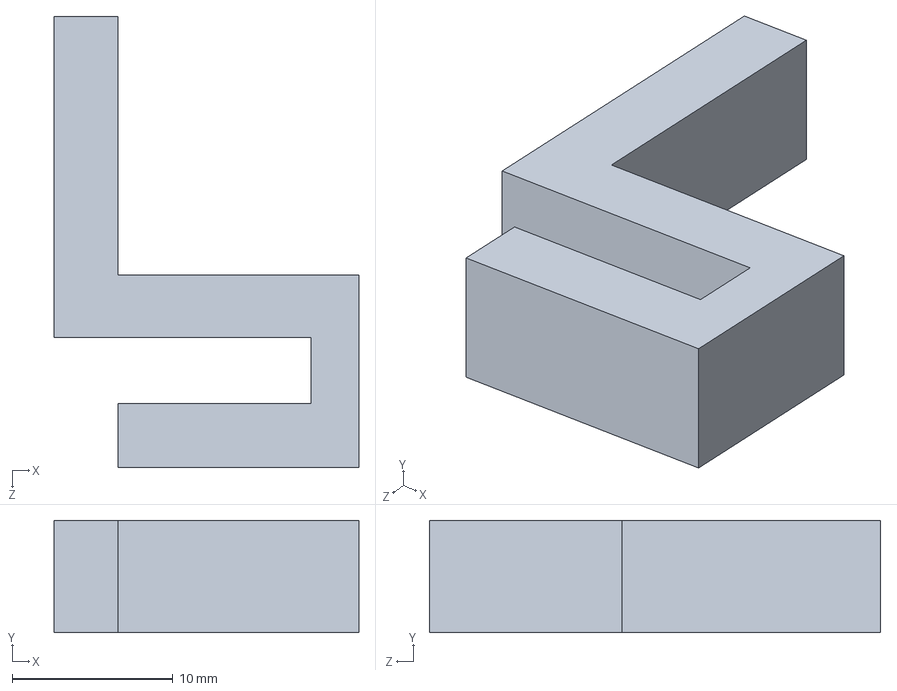
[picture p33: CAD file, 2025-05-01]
Task 1/4-Battery slide in key solidpart.SLDPRT
19.0 x 7.00 x 28.1 mm

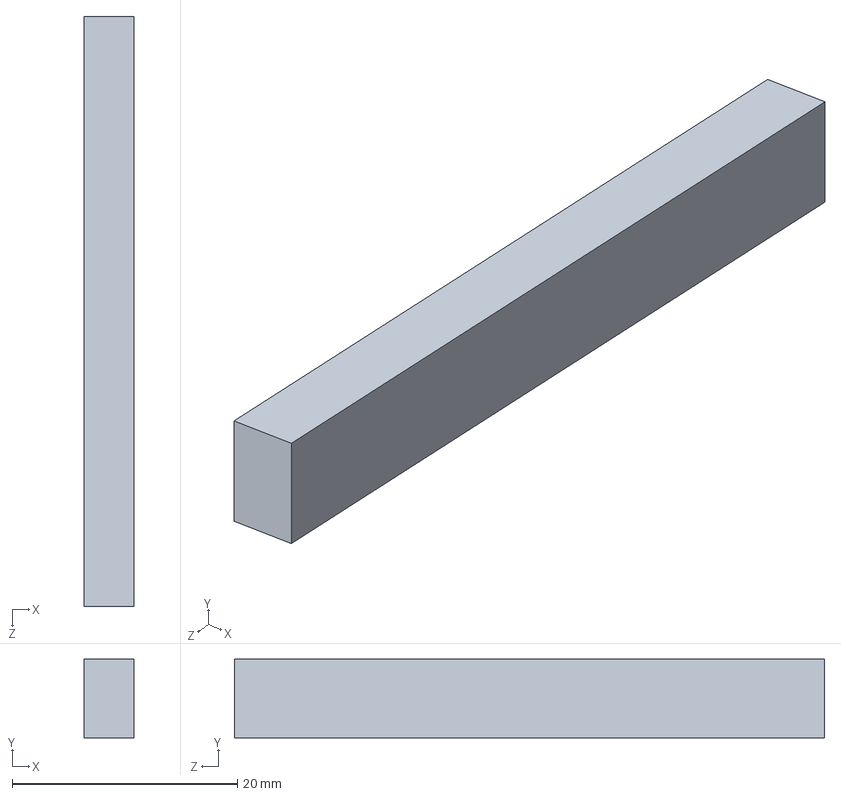
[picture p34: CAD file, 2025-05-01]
Task 1/LOCK-2_Solidpart.SLDPRT
4.40 x 7.00 x 52.4 mm

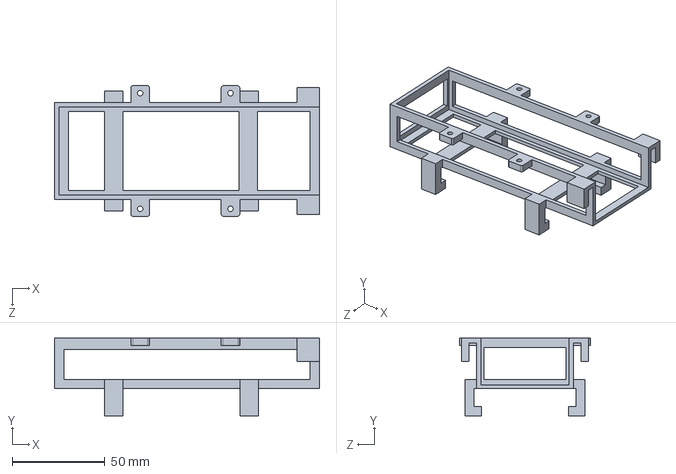
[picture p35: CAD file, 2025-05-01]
Task 1/3-Battery plus breadboard holder solidpart.SLDPRT
142.9 x 41.9 x 70.4 mm

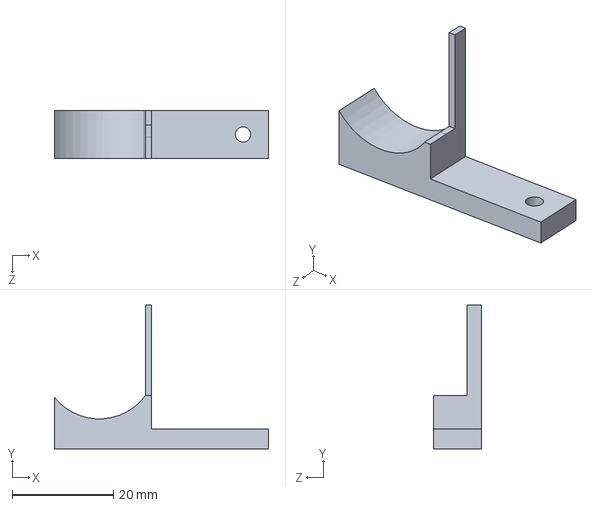
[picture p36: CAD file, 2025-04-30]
3D design for the car/final_motor_hold_2 solidpart.SLDPRT
42.2 x 28.4 x 9.41 mm

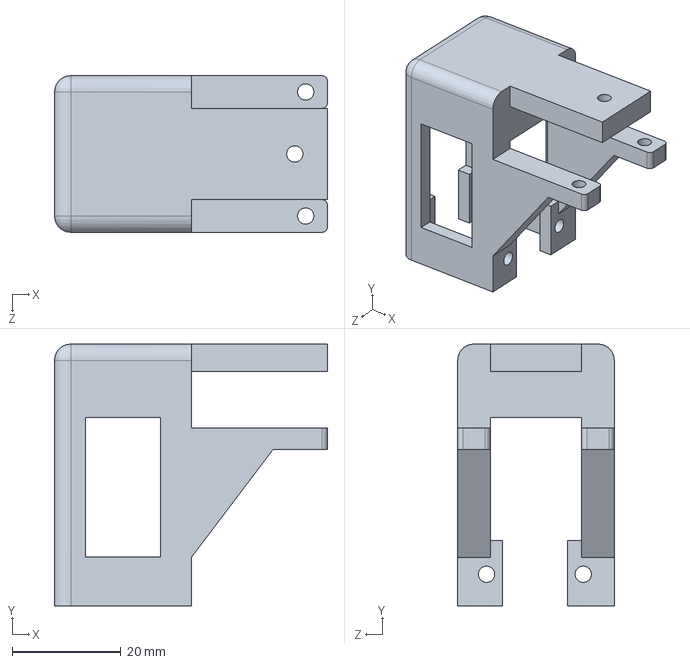
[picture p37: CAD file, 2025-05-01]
Task 1/5-motor holder solidpart.SLDPRT
50.1 x 48.1 x 28.8 mm

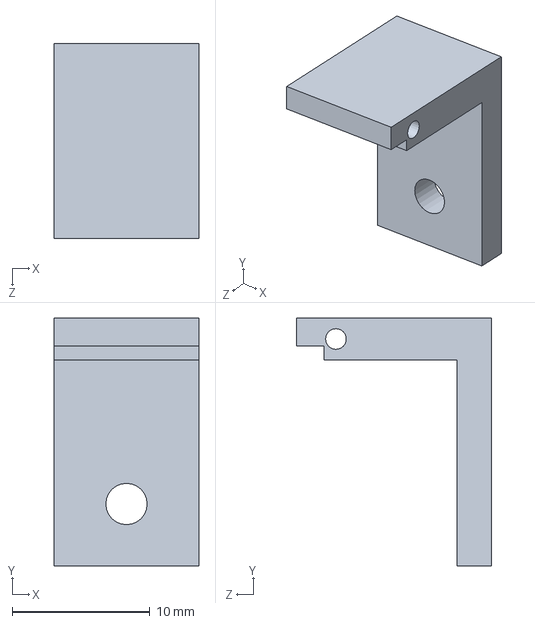
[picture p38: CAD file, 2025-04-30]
3D design for the car/final_IR_TOP_hold solidpart.SLDPRT
10.5 x 18.0 x 14.2 mm

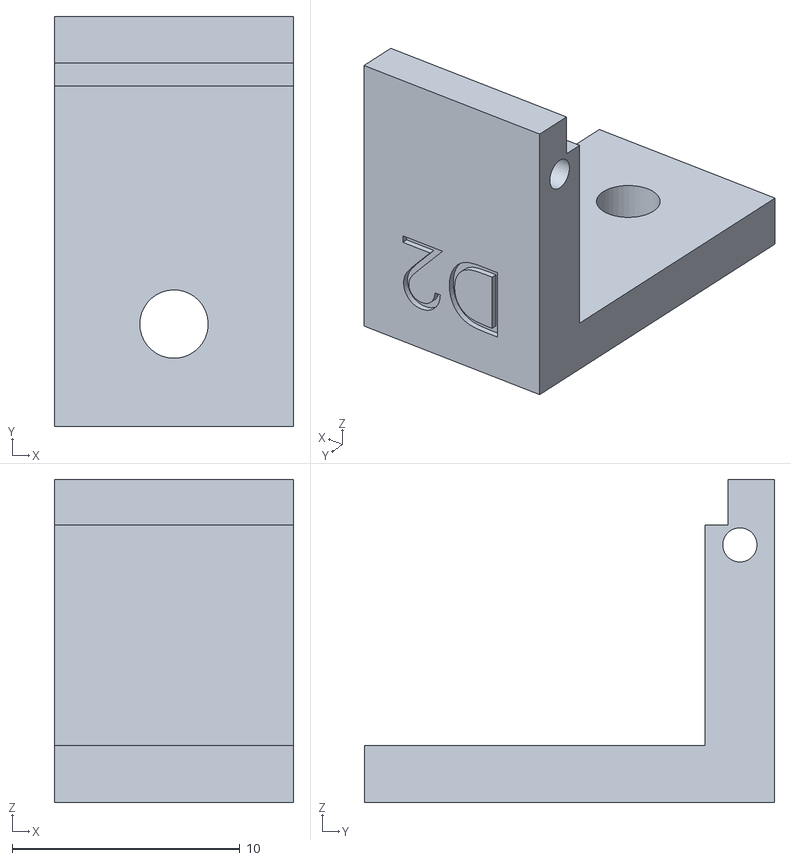
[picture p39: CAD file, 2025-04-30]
Task 1/IR_holder_TOP solidpart.STL
10.5 x 18.0 x 14.2

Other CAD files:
Task 1/2-IR_Sensor_Holder solidpart.SLDASM
3D design for the car/battery_holder_clip.STL
3D design for the car/battery_holder_clip solidpart.STL
3D design for the car/final_motor_HOLD_otherSide solidpart.SLDPRT
3D design for the car/final_battery_holder_key solidpart.SLDPRT
3D design for the car/final_motor_HOLD solidpart.SLDPRT
Task 1/FINAL_breadBoard_holder solidpart.SLDPRT
Task 1/FINAL_connector_pin_IR solidpart.SLDPRT
Task 1/IR_holder_BOTTOM solidpart.STL
Task 1/battery_holder_clip-2.STL
Task 1/bread_board_holder.STL
Task 1/connector_For_IR-solidpart.STL
Task 1/final_IR_HOLDER_BOTTOM solidpart.SLDPRT
Task 1/motor_holder_lower_chasis solidpart.STL
Task 1/motor_holder_top_mirror_side solidpart.STL
Task 1/new_ultrasonic_sensor solidpart.STL

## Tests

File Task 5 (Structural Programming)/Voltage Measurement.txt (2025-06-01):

# Voltage Measurement Protocol

Project: Line Following Robot  (D2)
Name:
Date: 01 June, 2025

---

## Tools Used
- Digital Multimeter: [Brand & Model, e.g., UNI-T UT33C+]
- Measurement Tolerance: ±0.01V
- Power Source: LiPo Battery (11.1V nominal, 12.6V full)

---

## Measurement Procedure

1. System powered on with full battery.
2. Measurements taken at key power distribution points:
   - VIN pin of Arduino
   - 5V output pin of Arduino
   - Motor driver VCC input
   - IR and ultrasonic sensor VCC pins

---

## Measurement Results

| Location | Expected Voltage | Measured Voltage |
|---|---|---|
| Battery Output (XT60 Connector) | 11.1 – 12.6 V | 11.7 V |
| Arduino VIN Pin | 11.1 – 12.6 V | 11.68 V |
| Arduino 5V Pin | 5.0 V | 4.99 V |
| Sensor VCC (IR, Ultrasonic) | 5.0 V | 5.00 V |
| Motor Driver VCC | 11.1 – 12.6 V | 11.7 V |

---

## Safety Check

- No major voltage drop observed.
- Sensors receive stable 5.0V from Arduino.
- Motor driver supplied directly from battery (works correctly).
- System construction (soldering) completed and inspected.

---

## Conclusion

✅ Power lines are stable and within expected range.  
✅ System is electrically safe and ready for operation.

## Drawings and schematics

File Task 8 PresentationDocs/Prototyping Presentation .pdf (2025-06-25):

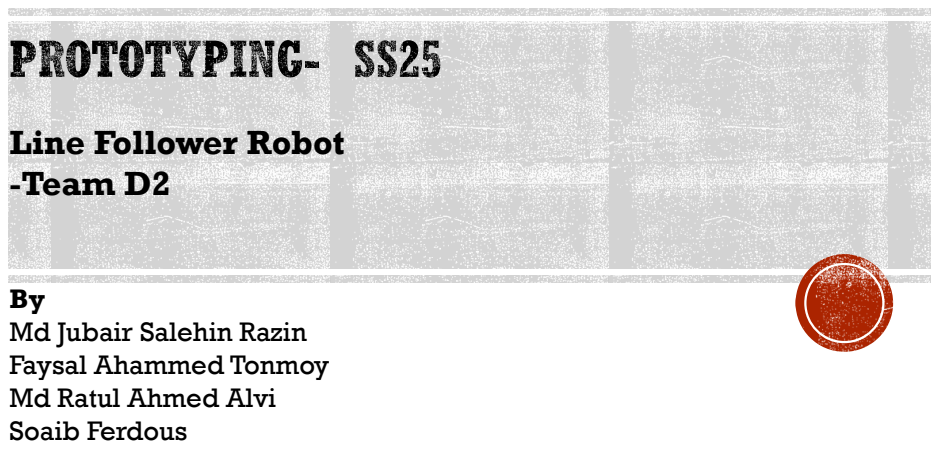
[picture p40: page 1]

Line Follower Robot
-Team D2

Md Jubair Salehin Razin
Faysal Ahammed Tonmoy
Md Ratul Ahmed Alvi
Soaib Ferdous

- Building Line Follower Robot powered by Arduino
- Equipped with ultrasonic sensors for detecting obstacles
- Follows black lines using infrared (IR) sensors
- Detects object colors using a color recognition sensor
- Driven by dual DC motors for smooth movement
- Includes a servo motor to help remove or bypass obstacles

Goal: To showcase intelligent navigation, smart obstacle detection and avoidance, color-based decision making, and adaptive robotic behavior using sensors and actuators.

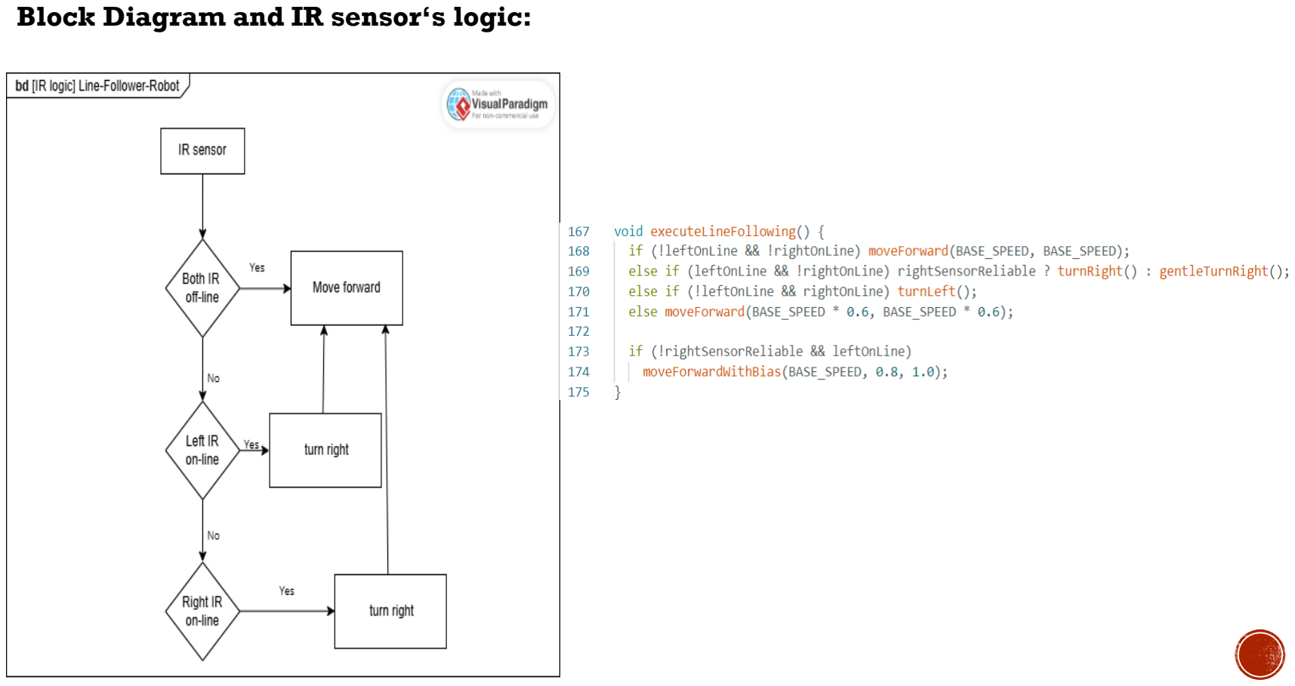
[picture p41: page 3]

Block Diagram and IR sensor‘s logic:

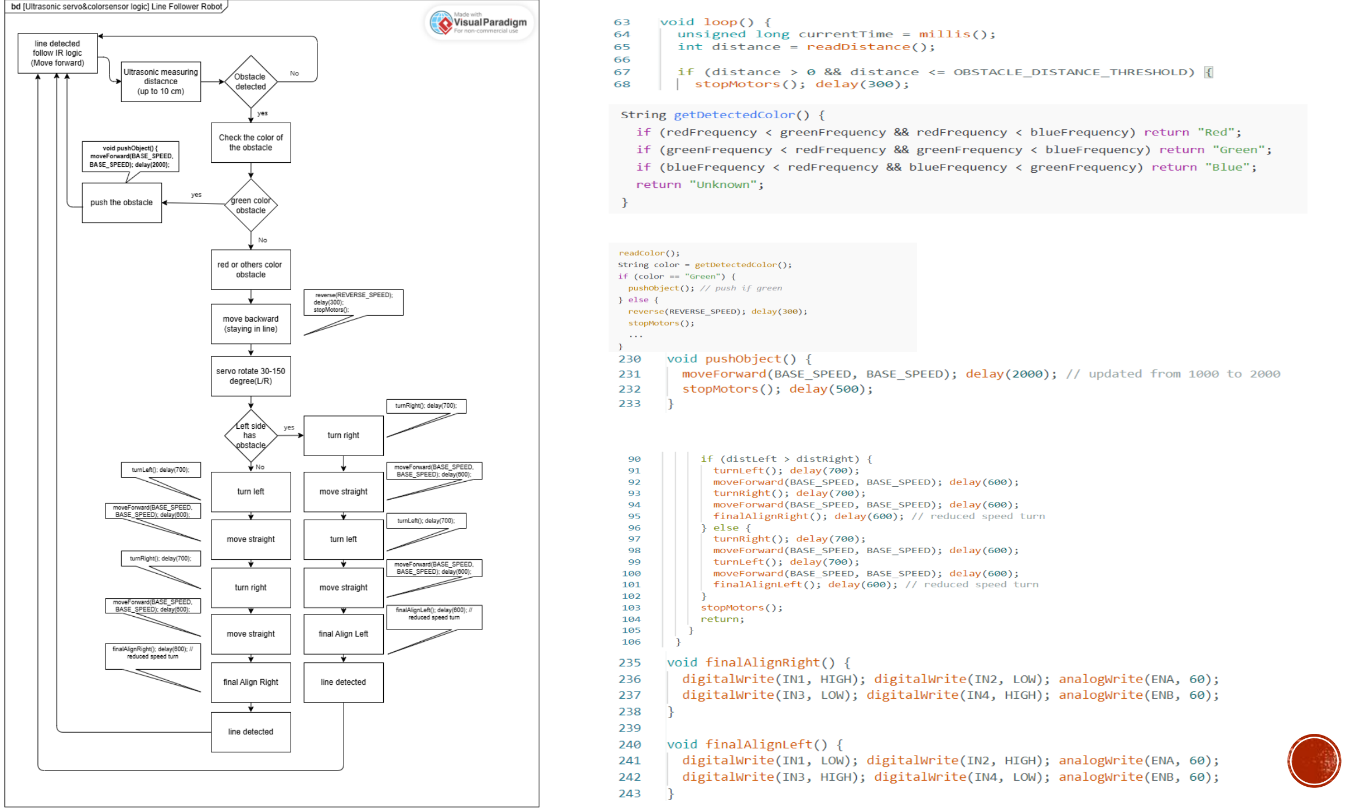
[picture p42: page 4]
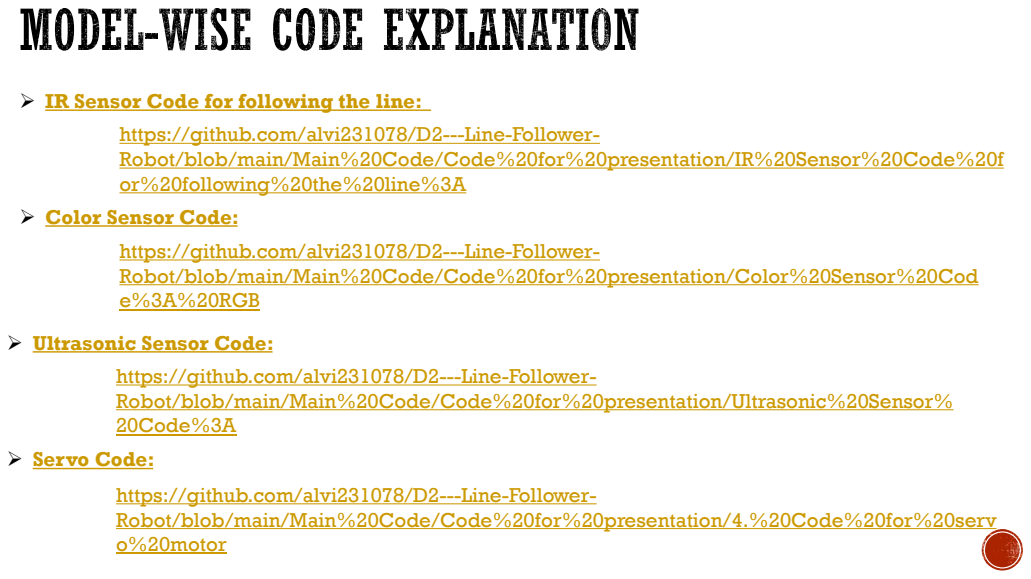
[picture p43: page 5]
➢ Servo Code:

➢ IR Sensor Code for following the line:

https://github.com/alvi231078/D2---Line-Follower-
Robot/blob/main/Main%20Code/Code%20for%20presentation/IR%20Sensor%20Code%20f
or%20following%20the%20line%3A

➢ Color Sensor Code:

Robot/blob/main/Main%20Code/Code%20for%20presentation/Color%20Sensor%20Cod
e%3A%20RGB (https://github.com/alvi231078/D2---Line-Follower-Robot/blob/main/Main%20Code/Code%20for%20presentation/Color%20Sensor%20Code%3A%20RGB)

➢ Ultrasonic Sensor Code:

Robot/blob/main/Main%20Code/Code%20for%20presentation/Ultrasonic%20Sensor%
20Code%3A

Robot/blob/main/Main%20Code/Code%20for%20presentation/4.%20Code%20for%20serv
o%20motor (https://github.com/alvi231078/D2---Line-Follower-Robot/blob/main/Main%20Code/Code%20for%20presentation/4.%20Code%20for%20servo%20motor)

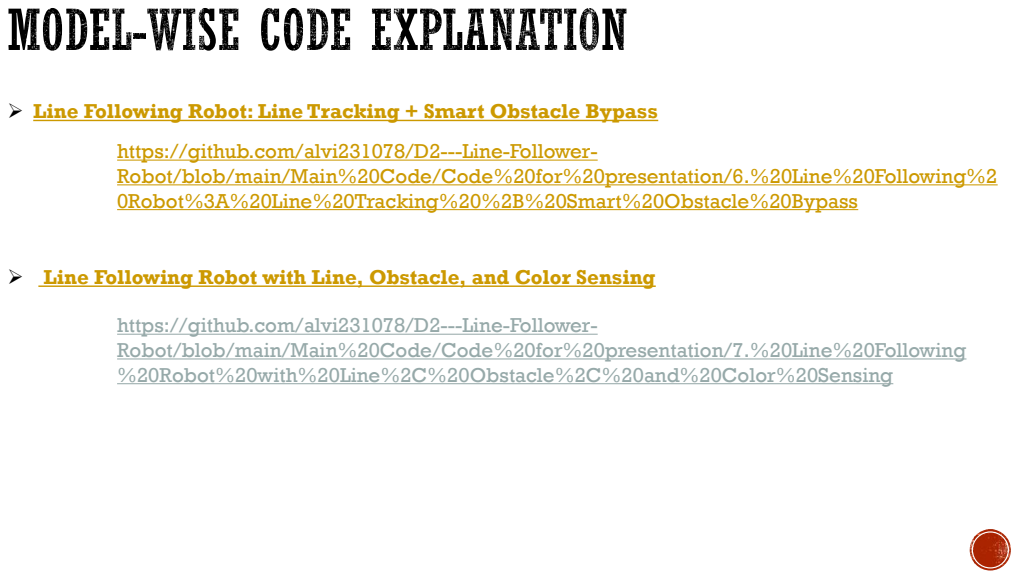
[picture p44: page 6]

➢ Line Following Robot: Line Tracking + Smart Obstacle Bypass

https://github.com/alvi231078/D2---Line-Follower-
Robot/blob/main/Main%20Code/Code%20for%20presentation/6.%20Line%20Following%2
0Robot%3A%20Line%20Tracking%20%2B%20Smart%20Obstacle%20Bypass

➢ Line Following Robot with Line, Obstacle, and Color Sensing

Robot/blob/main/Main%20Code/Code%20for%20presentation/7.%20Line%20Following
%20Robot%20with%20Line%2C%20Obstacle%2C%20and%20Color%20Sensing

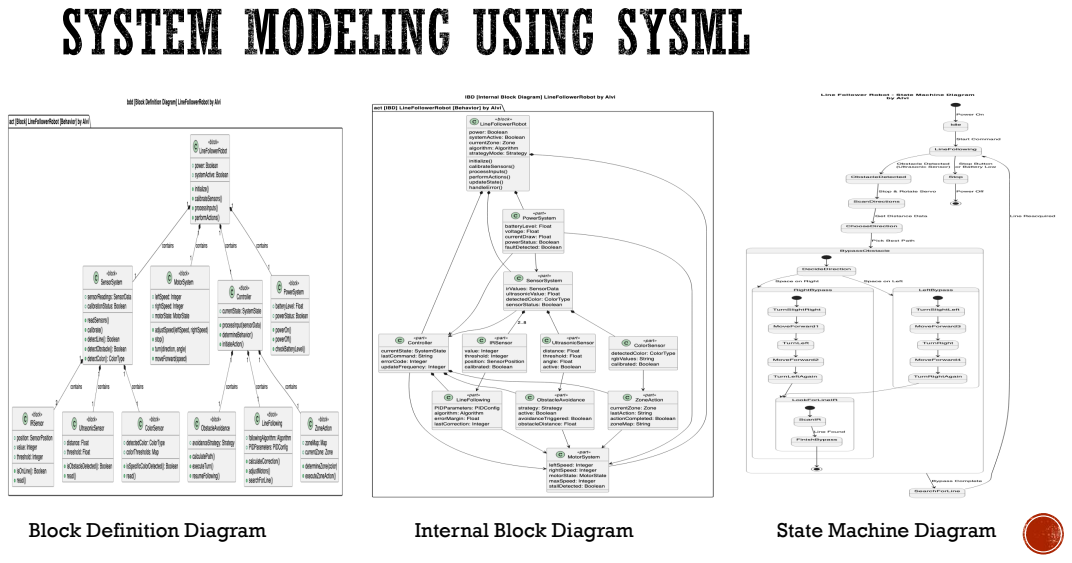
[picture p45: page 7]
Block Definition Diagram; Internal Block Diagram; State Machine Diagram

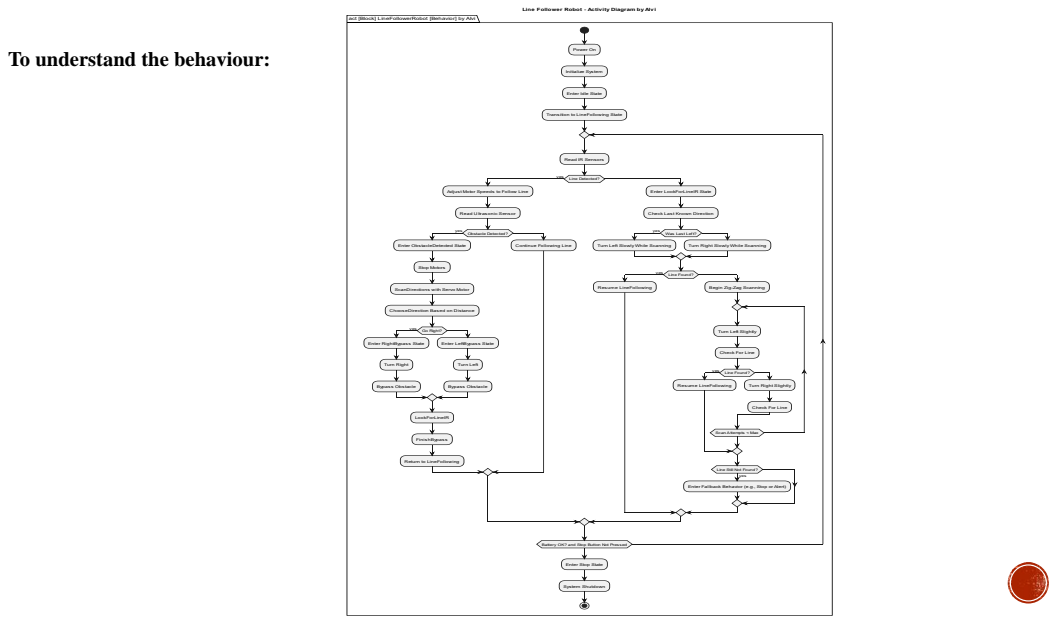
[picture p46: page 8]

To understand the behaviour:

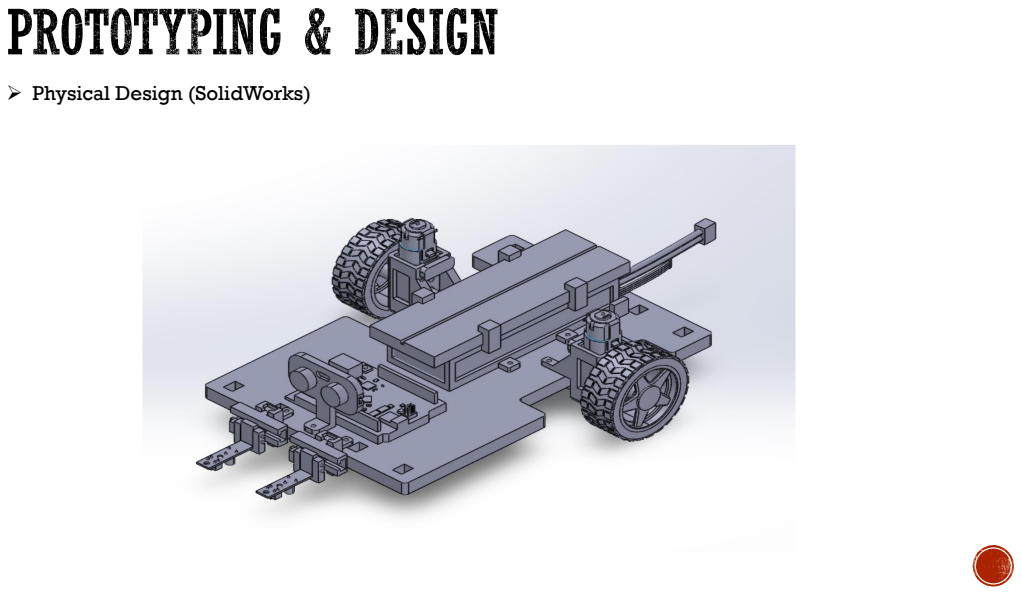
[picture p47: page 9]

➢ Physical Design (SolidWorks)

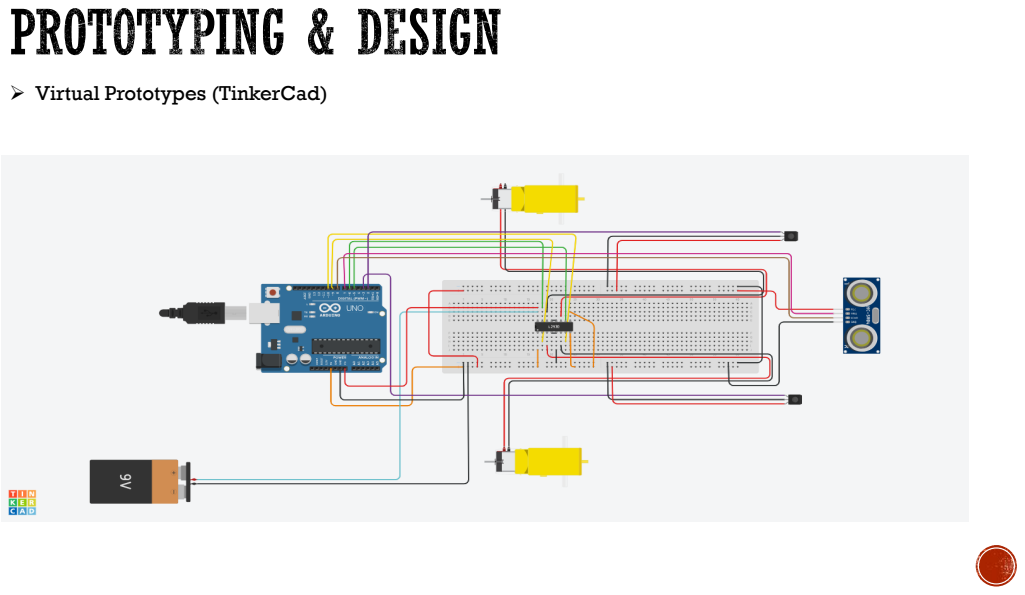
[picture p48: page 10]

➢ Virtual Prototypes (TinkerCad)

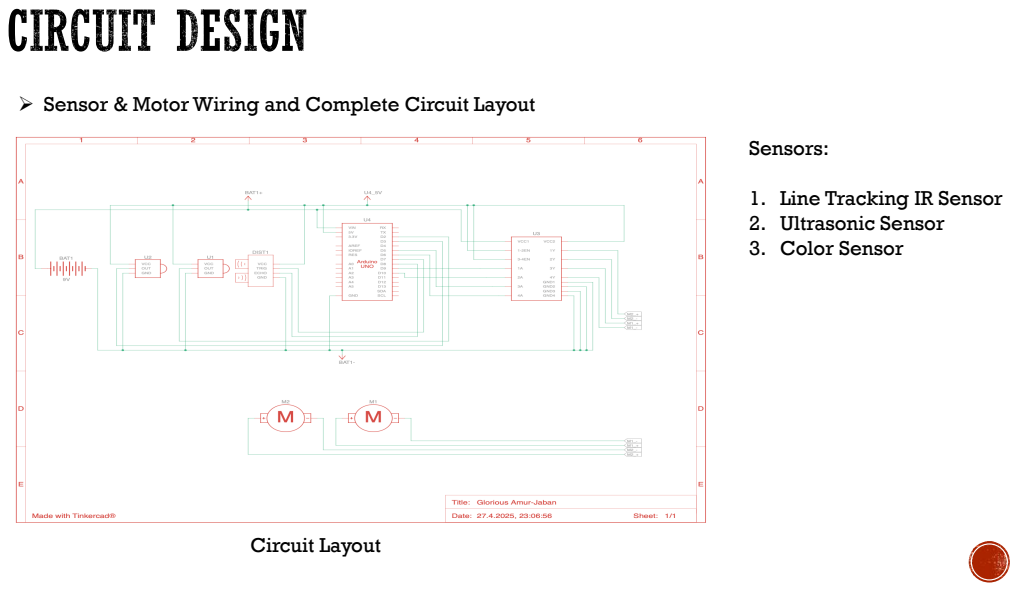
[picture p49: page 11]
Circuit Layout; Sensors:

➢ Sensor & Motor Wiring and Complete Circuit Layout

1. Line Tracking IR Sensor
2. Ultrasonic Sensor
3. Color Sensor

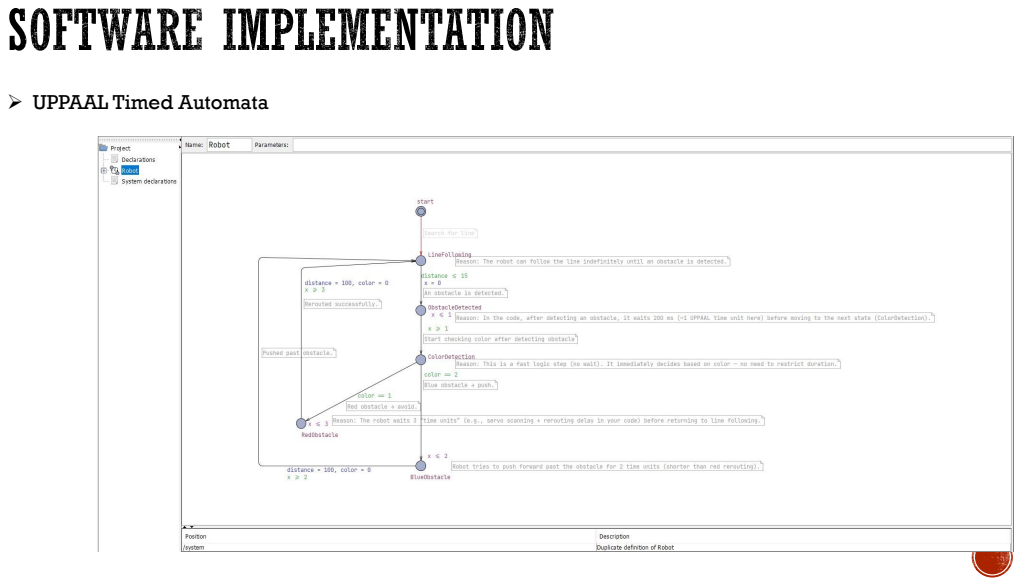
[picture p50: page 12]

➢ UPPAAL Timed Automata

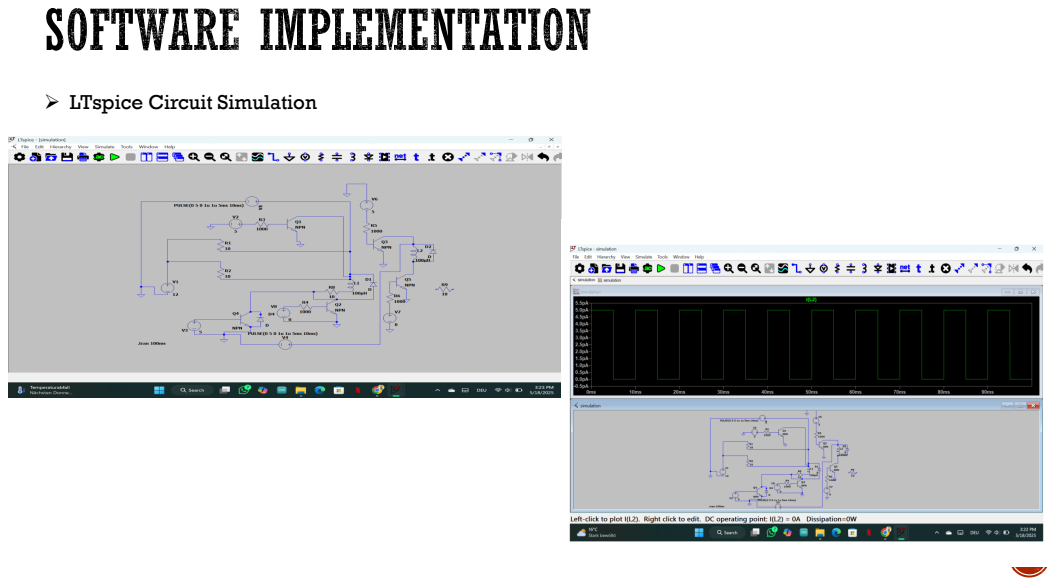
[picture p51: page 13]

➢ LTspice Circuit Simulation


▪ https://youtu.be/kWiVvY1VcH8?si=XqxR6bjObIauFDW2

Collaborative Outcomes:; Autonomous Navigation

Integrated Multi-Sensor System

Robust Embedded Design

Applied SysML & UML Thinking

Design Principles Used

This project showcases an autonomous embedded system combining line tracking, obstacle avoidance, and
color-based decisions forming a foundation for future intelligent robotics.

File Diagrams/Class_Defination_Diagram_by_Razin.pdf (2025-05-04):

- speed: float - direction: String - sensorData:Array - lineDetected: bool - position: tuple - motorState: String; + start() + stop() + followLine(): void + readSensors(): array + adjustDirection(): void; MotorDriver; - motorL1: int - motorL2: int - motorR1: int - motorR2: int - motorSpeed: int; IRSensor; - pin: int; + isLineDetected(): bool; UltrasonicSensor; - trigPin: int - echoPin: int; + getDistanceCM(): long; ColorSensor; - S0: int - S1: int - S2: int - S3: int - sensorOut: int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

Autonomous line follower car

+ digitalWrite(pin: int, value: int): void
+ digitalRead(pin: int): int
+ analogWrite(pin: int, value: int): void
+ analogRead(pin: int): int
+ delay(ms: int): void
+ millis(): unsigned long

+ rotateTo(degree: int): void
+ attachSensor(sensor: String): void

+ moveForward(): void
+ stopMotors(): void
+ turnLeft(): void
+ turnRight(): void
+ setSpeed(speed: int): void

- readColor(): String
+ readColorFrequency(s2Val: bool, s3Val: bool): int

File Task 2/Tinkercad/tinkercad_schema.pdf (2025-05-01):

A

1 | 2 | 3 | 4 | 5 | 6


Title: Glorious Amur-Jaban

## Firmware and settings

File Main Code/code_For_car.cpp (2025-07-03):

// === Includes and Constants ===
#include <Servo.h>

// Motor driver pins
const int ENA = 10, ENB = 11;
const int IN1 = 5, IN2 = 6, IN3 = 7, IN4 = 8;

// IR sensor pins
const int LEFT_SENSOR = 3, RIGHT_SENSOR = 4;

// Speed settings
const int BASE_SPEED = 90, TURN_SPEED = 70, REVERSE_SPEED = 70;

// IR logic & control
const bool LINE_DETECTED_STATE = false;
const int LOOP_DELAY = 8, SENSOR_READ_INTERVAL = 2, SENSOR_SAMPLES = 3;

// Ultrasonic sensor
const int TRIG_PIN = 13, ECHO_PIN = 12, OBSTACLE_DISTANCE_THRESHOLD = 10;

// Color sensor pins
const int COLOR_S0 = A0, COLOR_S1 = A1, COLOR_S2 = A2, COLOR_S3 = A3, COLOR_OUT = A4, COLOR_LED = A5;

// Battery voltage monitoring
const int BATTERY_PIN = A6;
const float VOLTAGE_THRESHOLD = 4.0;

Servo myServo;

// State variables
unsigned long lastSensorRead = 0, lastDebugPrint = 0;
const int DEBUG_INTERVAL = 200;
bool leftOnLine = false, rightOnLine = false;
bool rightSensorReliable = true;
unsigned long rightSensorLastDetected = 0;
int leftSensorHistory[SENSOR_SAMPLES] = {}, rightSensorHistory[SENSOR_SAMPLES] = {}, sampleIndex = 0;

// Color sensor readings
int redFrequency = 0, greenFrequency = 0, blueFrequency = 0;

void setup() {
  pinMode(ENA, OUTPUT); pinMode(ENB, OUTPUT);
  pinMode(IN1, OUTPUT); pinMode(IN2, OUTPUT);
  pinMode(IN3, OUTPUT); pinMode(IN4, OUTPUT);
  pinMode(LEFT_SENSOR, INPUT); pinMode(RIGHT_SENSOR, INPUT);
  pinMode(TRIG_PIN, OUTPUT); pinMode(ECHO_PIN, INPUT);

  pinMode(COLOR_S0, OUTPUT); pinMode(COLOR_S1, OUTPUT);
  pinMode(COLOR_S2, OUTPUT); pinMode(COLOR_S3, OUTPUT);
  pinMode(COLOR_LED, OUTPUT); pinMode(COLOR_OUT, INPUT);
  digitalWrite(COLOR_S0, HIGH); digitalWrite(COLOR_S1, LOW);
  digitalWrite(COLOR_LED, HIGH);

  myServo.attach(9); myServo.write(90);
  Serial.begin(9600); while (!Serial);
  Serial.println("LFR + Obstacle Avoidance + Color Detection Init");
  stopMotors(); delay(1000);
}

void loop() {
  unsigned long currentTime = millis();
  int distance = readDistance();

  // Battery voltage monitor
  float batteryVoltage = readBatteryVoltage();
  int motorSpeed = (batteryVoltage < VOLTAGE_THRESHOLD) ? BASE_SPEED : BASE_SPEED;

  if (distance > 0 && distance <= OBSTACLE_DISTANCE_THRESHOLD) {
    stopMotors(); delay(300);
    readColor();
    String color = getDetectedColor();
    Serial.print("R:"); Serial.print(redFrequency);
    Serial.print(" G:"); Serial.print(greenFrequency);
    Serial.print(" B:"); Serial.print(blueFrequency);
    Serial.print(" | Distance: "); Serial.print(distance);
    Serial.print(" cm | Detected Color: "); Serial.println(color);

    if (color == "Green") {
      pushObject();
      return;
    } else {
      reverse(REVERSE_SPEED); delay(300);
      stopMotors();

      myServo.write(150); delay(500); int distRight = readDistance();
      myServo.write(30); delay(500); int distLeft = readDistance();
      myServo.write(90); delay(300);

      if (distLeft > distRight) {
        turnLeft(); delay(700);
        moveForward(motorSpeed, motorSpeed); delay(600);
        turnRight(); delay(700);
        moveForward(motorSpeed, motorSpeed); delay(600);
        finalAlignRight(); delay(600);
      } else {
        turnRight(); delay(700);
        moveForward(motorSpeed, motorSpeed); delay(600);
        turnLeft(); delay(700);
        moveForward(motorSpeed, motorSpeed); delay(600);
        finalAlignLeft(); delay(600);
      }
      stopMotors();
      return;
    }
  }

  if (currentTime - lastSensorRead >= SENSOR_READ_INTERVAL) {
    readSensors(); lastSensorRead = currentTime;
  }

  executeLineFollowing();

  if (currentTime - lastDebugPrint >= DEBUG_INTERVAL) {
    printDebugInfo(); lastDebugPrint = currentTime;
  }

  delay(LOOP_DELAY);
}

// === Helper Functions ===

float readBatteryVoltage() {
  int sensorValue = analogRead(BATTERY_PIN);
  return sensorValue * (5.0 / 1023.0) * 2;
}

void readColor() {
  redFrequency = readColorFrequency(LOW, LOW);
  greenFrequency = readColorFrequency(HIGH, HIGH);
  blueFrequency = readColorFrequency(LOW, HIGH);
}

int readColorFrequency(bool s2, bool s3) {
  digitalWrite(COLOR_S2, s2); digitalWrite(COLOR_S3, s3);
  delay(100);
  return pulseIn(COLOR_OUT, LOW);
}

String getDetectedColor() {
  if (redFrequency < greenFrequency && redFrequency < blueFrequency) return "Red";
  if (greenFrequency < redFrequency && greenFrequency < blueFrequency) return "Green";
  if (blueFrequency < redFrequency && blueFrequency < greenFrequency) return "Blue";
  return "Unknown";
}

void readSensors() {
  int leftTotal = 0, rightTotal = 0;
  for (int i = 0; i < 3; i++) {
    leftTotal += digitalRead(LEFT_SENSOR);
    rightTotal += digitalRead(RIGHT_SENSOR);
    delayMicroseconds(500);
  }
  bool leftRaw = (leftTotal >= 2), rightRaw = (rightTotal >= 2);
  leftSensorHistory[sampleIndex] = leftRaw;
  rightSensorHistory[sampleIndex] = rightRaw;

  int leftSum = 0, rightSum = 0;
  for (int i = 0; i < SENSOR_SAMPLES; i++) {
    leftSum += leftSensorHistory[i];
    rightSum += rightSensorHistory[i];
  }

  leftOnLine = (leftSum >= (SENSOR_SAMPLES / 2 + 1)) == LINE_DETECTED_STATE;
  rightOnLine = (rightSum >= (SENSOR_SAMPLES / 2 + 1)) == LINE_DETECTED_STATE;

  if (rightOnLine) {
    rightSensorLastDetected = millis(); rightSensorReliable = true;
  } else if (millis() - rightSensorLastDetected > 5000) {
    rightSensorReliable = false;
  }

  sampleIndex = (sampleIndex + 1) % SENSOR_SAMPLES;
}

void executeLineFollowing() {
  if (!leftOnLine && !rightOnLine)
    moveForward(BASE_SPEED, BASE_SPEED);
  else if (leftOnLine && !rightOnLine)
    rightSensorReliable ? turnRight() : gentleTurnRight();
  else if (!leftOnLine && rightOnLine)
    turnLeft();
  else
    moveForward(BASE_SPEED * 0.6, BASE_SPEED * 0.6);

  if (!rightSensorReliable && leftOnLine)
    moveForwardWithBias(BASE_SPEED, 0.8, 1.0);
}

void moveForward(int l, int r) {
  digitalWrite(IN1, HIGH); digitalWrite(IN2, LOW); analogWrite(ENA, l);
  digitalWrite(IN3, HIGH); digitalWrite(IN4, LOW); analogWrite(ENB, r);
}

void reverse(int speed) {
  digitalWrite(IN1, LOW); digitalWrite(IN2, HIGH); analogWrite(ENA, speed);
  digitalWrite(IN3, LOW); digitalWrite(IN4, HIGH); analogWrite(ENB, speed);
}

void stopMotors() {
  digitalWrite(IN1, LOW); digitalWrite(IN2, LOW);
  digitalWrite(IN3, LOW); digitalWrite(IN4, LOW);
  analogWrite(ENA, 0); analogWrite(ENB, 0);
}

void turnRight() {
  digitalWrite(IN1, HIGH); digitalWrite(IN2, LOW); analogWrite(ENA, TURN_SPEED);
  digitalWrite(IN3, LOW); digitalWrite(IN4, HIGH); analogWrite(ENB, TURN_SPEED * 0.7); // reduced speed for outer wheel
}

void turnLeft() {
  digitalWrite(IN1, LOW); digitalWrite(IN2, HIGH); analogWrite(ENA, TURN_SPEED * 0.7);
  digitalWrite(IN3, HIGH); digitalWrite(IN4, LOW); analogWrite(ENB, TURN_SPEED);
}

void gentleTurnRight() {
  digitalWrite(IN1, HIGH); digitalWrite(IN2, LOW); analogWrite(ENA, BASE_SPEED);
  digitalWrite(IN3, HIGH); digitalWrite(IN4, LOW); analogWrite(ENB, BASE_SPEED * 0.3);
}

void moveForwardWithBias(int base, float lBias, float rBias) {
  moveForward(base * lBias, base * rBias);
}

void printDebugInfo() {
  Serial.print("L:"); Serial.print(leftOnLine ? "■" : "□");
  Serial.print(" R:"); Serial.print(rightOnLine ? "■" : "□");
  if (!rightSensorReliable) Serial.print(" [R-FAULT]");
  Serial.print(" | ");
  if (!leftOnLine && !rightOnLine) Serial.println("FORWARD");
  else if (leftOnLine && !rightOnLine) Serial.println(rightSensorReliable ? "TURN RIGHT" : "GENTLE RIGHT");
  else if (!leftOnLine && rightOnLine) Serial.println("TURN LEFT");
  else Serial.println("BOTH ON LINE");
}

int readDistance() {
  digitalWrite(TRIG_PIN, LOW); delayMicroseconds(2);
  digitalWrite(TRIG_PIN, HIGH); delayMicroseconds(10);
  digitalWrite(TRIG_PIN, LOW);
  return pulseIn(ECHO_PIN, HIGH) * 0.034 / 2;
}

void pushObject() {
  moveForward(BASE_SPEED, BASE_SPEED); delay(2000);
  stopMotors(); delay(500);
}

void finalAlignRight() {
  digitalWrite(IN1, HIGH); digitalWrite(IN2, LOW); analogWrite(ENA, 60);
  digitalWrite(IN3, LOW); digitalWrite(IN4, HIGH); analogWrite(ENB, 60);
}

void finalAlignLeft() {
  digitalWrite(IN1, LOW); digitalWrite(IN2, HIGH); analogWrite(ENA, 60);
  digitalWrite(IN3, HIGH); digitalWrite(IN4, LOW); analogWrite(ENB, 60);
}

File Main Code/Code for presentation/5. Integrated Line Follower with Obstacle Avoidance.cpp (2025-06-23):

// === Includes ===
#include <Servo.h>

// === Motor Driver Pins ===
const int ENA = 10;
const int ENB = 11;
const int IN1 = 5;
const int IN2 = 6;
const int IN3 = 7;
const int IN4 = 8;

// === IR Sensor Pins ===
const int LEFT_SENSOR  = 3;
const int RIGHT_SENSOR = 4;

// === Speed Settings ===
const int BASE_SPEED    = 90;
const int TURN_SPEED    = 70;
const int REVERSE_SPEED = 70;

// === IR Sensor Logic ===
const bool LINE_DETECTED_STATE = false;
const int LOOP_DELAY = 8;
const int SENSOR_READ_INTERVAL = 2;
const int SENSOR_SAMPLES = 3;

// === Ultrasonic Sensor Pins ===
const int TRIG_PIN = 13;
const int ECHO_PIN = 12;
const int OBSTACLE_DISTANCE_THRESHOLD = 10; // cm

// === Servo Motor ===
Servo myServo;

// === Sensor Filtering Variables ===
unsigned long lastSensorRead = 0;
unsigned long lastDebugPrint = 0;
const int DEBUG_INTERVAL = 200;

bool leftOnLine = false, rightOnLine = false;
bool prevLeftOnLine = false, prevRightOnLine = false;

int leftSensorHistory[SENSOR_SAMPLES] = {0};
int rightSensorHistory[SENSOR_SAMPLES] = {0};
int sampleIndex = 0;

bool rightSensorReliable = true;
unsigned long rightSensorLastDetected = 0;

void setup() {
  // === Setup Motor Pins ===
  pinMode(ENA, OUTPUT); pinMode(ENB, OUTPUT);
  pinMode(IN1, OUTPUT); pinMode(IN2, OUTPUT);
  pinMode(IN3, OUTPUT); pinMode(IN4, OUTPUT);

  // === Setup Sensors and Servo ===
  pinMode(LEFT_SENSOR, INPUT); pinMode(RIGHT_SENSOR, INPUT);
  pinMode(TRIG_PIN, OUTPUT); pinMode(ECHO_PIN, INPUT);
  myServo.attach(9);
  myServo.write(90); // Center position

  // === Serial Debugging ===
  Serial.begin(9600);
  while (!Serial); // Wait for Arduino UNO R4 WiFi
  Serial.println("LFR + Obstacle Avoidance Init");

  stopMotors();
  delay(1000);
}

void loop() {
  unsigned long currentTime = millis();

  // === Obstacle Check ===
  int distance = readDistance();
  if (distance > 0 && distance <= OBSTACLE_DISTANCE_THRESHOLD) {
    Serial.println("Obstacle <10cm - Stop, Reverse, Turn Servo Right");

    stopMotors();
    delay(300);

    reverse(REVERSE_SPEED);
    delay(500); // Move back

    stopMotors();
    myServo.write(150); // Look right
    delay(700);
    myServo.write(90);  // Reset to center
    delay(300);
    return; // Skip line following during obstacle
  }

  // === Sensor Reading and Line Following ===
  if (currentTime - lastSensorRead >= SENSOR_READ_INTERVAL) {
    readSensors();
    lastSensorRead = currentTime;
  }

  executeLineFollowing();

  // === Debug Output ===
  if (currentTime - lastDebugPrint >= DEBUG_INTERVAL) {
    printDebugInfo();
    lastDebugPrint = currentTime;
  }

  delay(LOOP_DELAY);
}

// === Read IR Sensors with Filtering ===
void readSensors() {
  prevLeftOnLine = leftOnLine;
  prevRightOnLine = rightOnLine;

  int leftTotal = 0, rightTotal = 0;
  for (int i = 0; i < 3; i++) {
    leftTotal += digitalRead(LEFT_SENSOR);
    rightTotal += digitalRead(RIGHT_SENSOR);
    delayMicroseconds(500);
  }

  bool leftRaw = (leftTotal >= 2);
  bool rightRaw = (rightTotal >= 2);

  leftSensorHistory[sampleIndex] = leftRaw;
  rightSensorHistory[sampleIndex] = rightRaw;

  int leftSum = 0, rightSum = 0;
  for (int i = 0; i < SENSOR_SAMPLES; i++) {
    leftSum += leftSensorHistory[i];
    rightSum += rightSensorHistory[i];
  }

  bool leftFiltered = (leftSum >= (SENSOR_SAMPLES / 2 + 1));
  bool rightFiltered = (rightSum >= (SENSOR_SAMPLES / 2 + 1));

  leftOnLine = (leftFiltered == LINE_DETECTED_STATE);
  rightOnLine = (rightFiltered == LINE_DETECTED_STATE);

  if (rightOnLine) {
    rightSensorLastDetected = millis();
    rightSensorReliable = true;
  } else if (millis() - rightSensorLastDetected > 5000) {
    rightSensorReliable = false;
  }

  sampleIndex = (sampleIndex + 1) % SENSOR_SAMPLES;
}

// === Line Following Motor Control ===
void executeLineFollowing() {
  if (!leftOnLine && !rightOnLine) {
    moveForward(BASE_SPEED, BASE_SPEED);
  } else if (leftOnLine && !rightOnLine) {
    if (!rightSensorReliable) gentleTurnRight();
    else turnRight();
  } else if (!leftOnLine && rightOnLine) {
    turnLeft();
  } else {
    moveForward(BASE_SPEED * 0.6, BASE_SPEED * 0.6);
  }

  if (!rightSensorReliable && leftOnLine) {
    moveForwardWithBias(BASE_SPEED, 0.8, 1.0);
  }
}

// === Motion Functions ===
void moveForward(int l, int r) {
  digitalWrite(IN1, HIGH); digitalWrite(IN2, LOW); analogWrite(ENA, l);
  digitalWrite(IN3, HIGH); digitalWrite(IN4, LOW); analogWrite(ENB, r);
}

void reverse(int speed) {
  digitalWrite(IN1, LOW); digitalWrite(IN2, HIGH); analogWrite(ENA, speed);
  digitalWrite(IN3, LOW); digitalWrite(IN4, HIGH); analogWrite(ENB, speed);
}

void stopMotors() {
  digitalWrite(IN1, LOW); digitalWrite(IN2, LOW);
  digitalWrite(IN3, LOW); digitalWrite(IN4, LOW);
  analogWrite(ENA, 0); analogWrite(ENB, 0);
}

void turnRight() {
  digitalWrite(IN1, HIGH); digitalWrite(IN2, LOW); analogWrite(ENA, TURN_SPEED + 10);
  digitalWrite(IN3, LOW); digitalWrite(IN4, HIGH); analogWrite(ENB, REVERSE_SPEED);
}

void turnLeft() {
  digitalWrite(IN1, LOW); digitalWrite(IN2, HIGH); analogWrite(ENA, REVERSE_SPEED);
  digitalWrite(IN3, HIGH); digitalWrite(IN4, LOW); analogWrite(ENB, TURN_SPEED + 10);
}

void gentleTurnRight() {
  digitalWrite(IN1, HIGH); digitalWrite(IN2, LOW); analogWrite(ENA, BASE_SPEED);
  digitalWrite(IN3, HIGH); digitalWrite(IN4, LOW); analogWrite(ENB, BASE_SPEED * 0.3);
}

void moveForwardWithBias(int base, float lBias, float rBias) {
  int l = base * lBias;
  int r = base * rBias;
  moveForward(l, r);
}

// === Serial Debug Info ===
void printDebugInfo() {
  Serial.print("L:"); Serial.print(leftOnLine ? "■" : "□");
  Serial.print(" R:"); Serial.print(rightOnLine ? "■" : "□");
  if (!rightSensorReliable) Serial.print(" [R-FAULT]");
  Serial.print(" | ");
  if (!leftOnLine && !rightOnLine) Serial.println("FORWARD");
  else if (leftOnLine && !rightOnLine) Serial.println(rightSensorReliable ? "TURN RIGHT" : "GENTLE RIGHT");
  else if (!leftOnLine && rightOnLine) Serial.println("TURN LEFT");
  else Serial.println("BOTH ON LINE");
}

// === Ultrasonic Sensor Distance Reading ===
int readDistance() {
  digitalWrite(TRIG_PIN, LOW);
  delayMicroseconds(2);
  digitalWrite(TRIG_PIN, HIGH);
  delayMicroseconds(10);
  digitalWrite(TRIG_PIN, LOW);
  long duration = pulseIn(ECHO_PIN, HIGH);
  return duration * 0.034 / 2; // Convert to cm
}

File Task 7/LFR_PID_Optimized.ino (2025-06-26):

// === PID Variables ===
float Kp = 25;
float Ki = 0.01;
float Kd = 10;

int error = 0;
float integral = 0;
int previous_error = 0;

// === Updated executeLineFollowing() function using PID ===
void executeLineFollowing() {
  // Step 1: Calculate error based on IR sensor states
  if (leftOnLine && !rightOnLine) {
    error = -1;  // drifted to the right
  } else if (!leftOnLine && rightOnLine) {
    error = 1;   // drifted to the left
  } else if (!leftOnLine && !rightOnLine) {
    error = 2;   // completely lost the line
  } else {
    error = 0;   // centered
  }

  // Step 2: PID calculation
  integral += error;
  int derivative = error - previous_error;
  int correction = Kp * error + Ki * integral + Kd * derivative;
  previous_error = error;

  // Step 3: Adjust motor speeds based on correction
  int leftSpeed = BASE_SPEED - correction;
  int rightSpeed = BASE_SPEED + correction;

  // Make sure speed stays within safe PWM range
  leftSpeed = constrain(leftSpeed, 0, 255);
  rightSpeed = constrain(rightSpeed, 0, 255);

  // Step 4: Move the motors with adjusted speeds
  moveForward(leftSpeed, rightSpeed);
}

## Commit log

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2025-04-30 Added the code for IR sensor to detect black line
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2025-04-30 full_parts_of_ir_sensor_holder
    IR sensor holder which will connect to Chassis
    [IR_Sensor_Holder.SLDASM]
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2025-04-30 Separate parts
    [final IR top holder.SLDPRT, final battery holder key.SLDPRT, final bread board holder.SLDPRT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]
2025-04-30 Rename Final Car Assemble.pdf to 01-Final Car Assemble.pdf
2025-04-30 Complete Assembly of IR sensor
    [02-IR_Sensor_Holder.SLDASM]
2025-04-30 updated car code uss
    updated car code to fit ultrasonic senrorr
2025-04-30 Updated buggy code
    Updated code because it gave error before
    [code_For_car.cpp]
2025-04-30 Update code_For_car.cpp
    finding difficulty running motor on max speed
2025-04-30 Update code_For_car.cpp
    added buzzer for fun
    [code_For_car.cpp]
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2025-05-01 Update code_For_car.cpp
    Added logic for precise line following with IR sensors
2025-05-01 algorithm for case when both ir sees white updated
2025-05-01 added bug fixes and checks for error
    [code_For_car.cpp]
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2025-05-01 updated multiple files
    [battery_holder_clip.STL]
2025-05-01 Updated battery + breadboard holder
    [Battery plus breadboard holder.SLDPRT]
2025-05-01 File updated 03-Battery plus breadboard holder.SLDPRT
    [03-Battery plus breadboard holder.SLDPRT]
2025-05-01 Updated battery slide in/out key
    [Battery slide in key.SLDPRT]
2025-05-01 Updated file 04-Battery slide in key.SLDPRT
    [04-Battery slide in key.SLDPRT]
2025-05-01 05-Motor holder
    [motor holder.SLDPRT]
2025-05-01 Updated motor holder.SLDPRT
    [05-motor holder.SLDPRT]
2025-05-01 Motor holder pin
    [motor holder pin.SLDPRT]
2025-05-01 Updated motor holder pin.SLDPRT
    [06-motor holder pin.SLDPRT]
2025-05-01 Lock to hold the battery
    [lock 2.SLDPRT]
2025-05-01 Complete Car Assemble.pdf
    Assembled Final Autonomous Line Follower Car:
    All core modules have been successfully integrated into a single, fully functional prototype of the autonomous line follower robot. This includes combining mechanical designs, sensor control, obstacl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
    The final assembly reflects a modular, maintainable, and scalable design approach, setting the foundation for further optimization in performance and efficiency.
    This commit ensures all previously developed and tested parts are logically structured and work together in a unified system.
2025-05-01 updated design file
    [lock 2.SLDPRT]
2025-05-01 Simulink model for DC motor control
    Created DC_Motor_Control_Arduino.slx to control two DC motors via L298N using Arduino Uno.
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2025-05-01 Planned Features- Color Detection Sensor
    For object recognition and based on the color it will take action
2025-05-01 Planned Features- Use logic blocks
    Switch between behaviors based on sensor inputs
2025-05-01 updated all files
    [02-IR_Sensor_Holder solidpart.SLDASM, 03-Battery plus breadboard holder solidpart.SLDPRT, 04-Battery slide in key solidpart.SLDPRT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]
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2025-05-02 updated design
    [5.1 motor holder updated.SLDPRT]
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2025-05-02 -
    .
    [bread_board_holder.STL]
2025-05-02 updated code and added connection for color sensor
2025-05-02 updated file
    [LOCK-2_Solidpart.SLDPRT]
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2025-05-02 Rename 02-IR_Sensor_Holder solidpart.SLDASM to 2-IR_Sensor_Holder solidpart.SLDASM
    [2-IR_Sensor_Holder solidpart.SLDASM]
2025-05-02 Rename 03-Battery plus breadboard holder solidpart.SLDPRT to 3-Battery plus breadboard holder solidpart.SLDPRT
    [3-Battery plus breadboard holder solidpart.SLDPRT]
2025-05-02 Rename 04-Battery slide in key solidpart.SLDPRT to 4-Battery slide in key solidpart.SLDPRT
    [4-Battery slide in key solidpart.SLDPRT]
2025-05-02 Rename 05-motor holder solidpart.SLDPRT to 5-motor holder solidpart.SLDPRT
    [5-motor holder solidpart.SLDPRT]
2025-05-02 Rename 06-motor holder pin solidpart.SLDPRT to 6-motor holder pin solidpart.SLDPRT
    [6-motor holder pin solidpart.SLDPRT]
2025-05-02 added error prevention logic and max failure timeout
    [code_For_car.cpp]
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2025-05-04 Simulink updated with IR sensor
    Updated complete Simulink model for DC motor control using IR sensors (D2, D3), connected to L298N motor driver via Arduino Uno. Includes logic for STOP, LEFT, RIGHT, and FORWARD actions using Multip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
2025-05-04 Update simulink.md
    Updated Simulink model for DC motor control using IR sensors (D2, D3), connected to L298N motor driver via Arduino Uno. Includes logic for STOP, LEFT, RIGHT, and FORWARD actions using Multiport Switc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
2025-05-15 coded so according to ir motor moves, first try, used pwm pins for ena and enab
2025-05-15 changed motor direction ulta ghure fix
    [code_For_car.cpp]
2025-05-15 motor turn fix
2025-05-15 basic code for testing motor movement according to ir signal
2025-05-15 added logic so car follows line no servo or uss yet
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2025-05-18 Add files via upload
    Current and Voltage behaviour
2025-05-31 Update and rename Modules to IR Sensor.cpp
    Code for the IR Sensor
2025-05-31 Create Ultrasonic Sensor.cpp
    Code for Ultra sonic Part
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2025-05-31 Create Colour sensor code
    Only colour sensor code for testing
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2025-05-31 Ultrasonic with servo motor
    added servo motor with ultrasonic sensor
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2025-06-07 All assembled parts
    [2-IR_Sensor_Holder solidpart.SLDASM, 3-Battery plus breadboard holder solidpart.SLDPRT, 4-Battery slide in key solidpart.SLDPRT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]
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2025-06-07 Uppaal simulation
    This model simulates the behavior of a line-following robot equipped with:
    Ultrasonic distance sensor
    Color detection sensor (Red / Blue obstacle)
    Servo motor to scan and steer
    It transitions between states based on:
    Real-time sensor readings
    Obstacle detection logic
    Obstacle color (Red = avoid; Blue = push)
    Delays mimicking physical motor and sensor response times
2025-06-07 Uppaal simulation-Timed Behavior
    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
2025-06-23 Rename IR Sensor Code for following the line: to 1. IR Sensor Code for following the line:
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2025-06-23 Rename Integrated Line Follower with Obstacle Avoidance.cpp to 5. Integrated Line Follower with Obstacle Avoidance.cpp
    [5. Integrated Line Follower with Obstacle Avoidance.cpp]
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
